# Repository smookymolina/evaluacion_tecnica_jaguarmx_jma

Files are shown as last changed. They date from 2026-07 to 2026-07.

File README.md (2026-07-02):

# Sistema de Extracción de Aire Caliente para Gabinete de Telecomunicaciones
## Jaguar de México — Evaluación Técnica
**Candidato:** Ing. Jair Molina Arce  
**Fecha:** 30 de junio de 2026

---

## Descripción del Proyecto
Este proyecto consiste en el diseño físico y lógico (hardware y firmware) de un sistema de control automático para la extracción de aire caliente en un gabinete de telecomunicaciones. El sistema compara la temperatura interna (`TEMP_INT`) con la temperatura externa (`TEMP_EXT`) y gestiona de forma dinámica:
1. **Compuertas mecánicas:** Operadas por un actuador lineal DFRobot FIT0803 a través de un puente H Toshiba TB6612FNG.
2. **Extractor/Ventilador:** Ventilador industrial Mechatronics MR1238E48B-FSR (48V DC) controlado por modulación low-side con un MOSFET de potencia IRL520N.

El núcleo de control está basado en el microcontrolador **Seeed Studio XIAO RP2350**, programado en MicroPython con una arquitectura de Máquina de Estados Finitos (FSM) y supervisado por un watchdog timer por hardware (WDT).

---

## Estructura del Repositorio

- `firmware/`: Código fuente de control en MicroPython.
  - `main.py`: Punto de entrada, inicialización y gestión de fallos.
  - `fsm.py`: Implementación de la FSM (INIT, READING, COOLING, IDLE, ERROR).
  - `adc_ntc.py`: Adquisición analógica con promedio móvil (trimmed mean, N=8) y conversión Beta.
  - `dip_switch.py`: Configuración de setpoint de histéresis mediante DIP switch.
  - `hbridge.py`: Control de dirección y habilitación del actuador con alimentación segura al WDT.
  - `fan.py`: Módulo de conmutación del MOSFET del ventilador.
- `kicad/`: Archivos del diseño de hardware en KiCad v8/v9.
  - `PCB/PCB.kicad_pro`: Archivo de proyecto de KiCad.
  - `PCB/PCB.kicad_sch`: Esquemático del circuito (Componentes colocados, especificaciones y BOM al 100%).
  - `PCB/PCB.kicad_pcb`: Diseño físico del PCB.
  - `PCB/sym-lib-table`: Tabla de mapeo de librerías de símbolos.
- `datasheets/`: Especificaciones técnicas en markdown y PDFs de los componentes clave.
- `FASE2.1_Netlist_Corregido_JaguarMX.md`: Netlist blindado de interconexiones (verdad de referencia).
- `FASE3_Guia_Esquematico_KiCad_JaguarMX.md`: Guía de diseño del esquemático.
- `FASE4_Layout_PCB_KiCad_JaguarMX.md`: Guía para el trazado de PCB y distribución de componentes.
- `ETISEJr_JairMolina.md`: Respuestas de evaluación y bitácora de uso de IA.
- `EvaluacionTecnica_SistemasEmbebidosJr_JaguarDeMexico.pdf`: Documento de requerimientos oficiales.
- `Cronograma_EvaluacionTecnica_JairMolina.docx`: Planificación de las fases del examen.
- `parse_sch.py`: Script para extraer la BOM directamente del esquemático KiCad.
- `test_firmware.py` / `micropython.py` / `mock_*.py`: Entorno local de pruebas unitarias y mocks de hardware.
- `package_project.ps1`: Script automatizado para el empaquetado del entregable final.

---

## Modificaciones de Hardware Incorporadas (Fase 2.1)
- **[MOD-1] Remapeo de SW2:** Movido de GP7 (back pad inaccesible) a GP8 (castellación lateral del Seeed XIAO RP2350).
- **[MOD-2] Clamping de ADC:** Reemplazo de diodos TVS SMBJ3.3A por diodos Schottky duales BAT54S en configuración de clamp activo post-filtro.
- **[MOD-3] Inmunidad EMI en DIP Switch:** Pull-ups externas de 10kΩ y condensadores de bypass de 100nF en cada canal.
- **[MOD-4] Selector J9:** Reemplazo del puente de soldadura por un header de 3 pines para seleccionar control del Gate directo o con driver TC4420.
- **[MOD-5] Star Ground:** Unión única AGND-PGND mediante Net-Tie de cobre directo (0Ω), eliminando la ferrita.
- **[Desacoplo de U4 (Nuevo)] Capacitor C15:** Adición del capacitor de desacoplo `C15` (100nF, DNP por defecto) para alimentar adecuadamente al driver TC4420 si se decide poblar en Configuración Activa-B.
- **[Conexión GND U4 (Nuevo)] Corrección de Plano:** Enrutamiento de la tierra de U4 (GND, pines 1, 2, 4) al plano de potencia `PGND` (en lugar del plano analógico `AGND`) para evitar la inyección de ruidos transitorios de 6A pico en el plano sensible de lectura.
- **[Consolidación (Nuevo)] Remoción de Excesos:** Eliminación de la resistencia fantasma redundante `R8` del diseño del circuito.

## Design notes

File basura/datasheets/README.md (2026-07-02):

# Datasheets — Sistema de Extracción de Aire Caliente
**Jaguar de México — Evaluación Técnica — Ing. Jair Molina Arce**

> Los archivos de esta carpeta son referencias técnicas para cada componente del sistema.
> Se incluyen dos fuentes por componente donde fue posible.
> **Los PDFs deben descargarse manualmente desde los links oficiales listados en cada archivo.**

---

## Índice de componentes

| Componente | Archivo | Función en el sistema |
|---|---|---|
| TB6612FNG | [TB6612FNG.md](TB6612FNG.md) | Puente H — control actuador FIT0803 |
| NTC TT05-10KC8-1S-T105-1500 | [NTC_TT05.md](NTC_TT05.md) | Sensor de temperatura ×2 |
| FIT0803 | [FIT0803.md](FIT0803.md) | Actuador lineal — compuertas |
| MR1238E48B-FSR | [MR1238E48B-FSR.md](MR1238E48B-FSR.md) | Ventilador 48V |
| IRL520N | [IRL520N.md](IRL520N.md) | MOSFET NMOS — etapa potencia ventilador |
| Seeed XIAO RP2350 | [XIAO_RP2350.md](XIAO_RP2350.md) | MCU (sesión en vivo) |
| RP2040 / Raspberry Pi Pico | [RP2040_Pico.md](RP2040_Pico.md) | MCU (simulación Wokwi) |
| AP2112K-3.3 | [AP2112K.md](AP2112K.md) | LDO 3.3V — regulador de tensión |
| 1N4007 | [1N4007.md](1N4007.md) | Diodo flyback — protección ventilador |
| SMBJ3.3A | [SMBJ3.3A.md](SMBJ3.3A.md) | TVS — protección entradas analógicas |

---

## Links de descarga directa (PDFs oficiales)

| Componente | Fuente 1 (oficial) | Fuente 2 (alternativa) |
|---|---|---|
| TB6612FNG | [Toshiba official](https://toshiba.semicon-storage.com/info/TB6612FNG_datasheet_en_20141001.pdf) | [SparkFun mirror](https://cdn.sparkfun.com/datasheets/Robotics/TB6612FNG.pdf) |
| NTC TT05 | [TME/TEWA official](https://www.tme.com/Document/878564d75c52f90722a06147eac94b00/TT05-10KC8-1S-T105-1500.pdf) | [DigiKey product page](https://www.digikey.com/en/products/detail/tewa-sensors-llc/TT05-10KC8-1S-T105-1500/10264792) |
| FIT0803 | [DFRobot (FIT080x series)](https://www.logosfoundation.org/instrum_gwr/sper/datasheets/DFRobot-FIT080x.pdf) | [DFRobot product page](https://www.dfrobot.com/product-2367.html) |
| MR1238E48B-FSR | [MinebeaMitsumi MR1238 series](https://www.mechatronics.com/pdf/MR1238.pdf) | [MinebeaMitsumi catalog](https://cdn.nmbtc.com/uploads/2025/04/202407-fan-motor-catalog-pdf.pdf) |
| IRL520N | [Infineon oficial](https://www.infineon.com/dgdl/Infineon-IRL520N-DataSheet-v01_01-EN.pdf?fileId=5546d462533600a40153565f9b62255b) | [Infineon assets](https://www.infineon.com/assets/row/public/documents/24/49/infineon-irl520n-datasheet-en.pdf) |
| XIAO RP2350 | [Seeed Studio Wiki](https://wiki.seeedstudio.com/getting-started-xiao-rp2350/) | [GitHub OSHW](https://github.com/Seeed-Studio/OSHW-XIAO-Series) |
| RP2040 | [RPi official](https://datasheets.raspberrypi.com/rp2040/rp2040-datasheet.pdf) | [Pico datasheet](https://datasheets.raspberrypi.com/pico/pico-datasheet.pdf) |
| AP2112K-3.3 | [Diodes Inc. official](https://www.diodes.com/assets/Datasheets/AP2112.pdf) | [Adafruit CDN](https://cdn-shop.adafruit.com/product-files/2471/AP2112.pdf) |
| 1N4007 | [Diodes Inc.](https://www.diodes.com/assets/Datasheets/ds28002.pdf) | [Mouser/Vishay](https://www.mouser.com/datasheet/2/149/1N4007-888322.pdf) |
| SMBJ3.3A | [Vishay SMBJ3V3](https://www.vishay.com/docs/88940/smbj3v3.pdf) | [Vishay SMBJ series](https://www.vishay.com/docs/88392/smbj.pdf) |

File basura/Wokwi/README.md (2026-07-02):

# Wokwi

Simulacion del sistema de ventilacion de aire caliente para Jaguar MX.

## Objetivo

La simulacion reproduce la logica del PDF de evaluacion:

- leer `TEMP_INT` y `TEMP_EXT`
- abrir compuertas y encender ventilador cuando `TEMP_INT > TEMP_EXT`
- apagar ventilador y cerrar compuertas cuando `TEMP_INT <= TEMP_EXT`
- entrar en estado seguro si alguna lectura NTC es invalida
- usar el DIP switch de 3 bits para seleccionar el setpoint de activación

## Archivos

- `diagram.json`: conexionado completo de la simulacion
- `sketch.ino`: firmware Arduino para Wokwi
- `tb6612fng-sim.chip.json`, `tb6612fng-sim.chip.c`: modelo del TB6612FNG
- `main.py`, `adc_ntc.py`, `dip_switch.py`, `fan.py`, `fsm.py`, `hbridge.py`: referencia MicroPython
- `MAPA_GPIO.md`: mapa rapido de pines

## Notas

- `GP26` y `GP27` simulan los NTC.
- `GP6`, `GP7` y `GP0` leen el DIP switch con `INPUT_PULLUP`.
- `GP2`, `GP1` y `GP3` controlan el TB6612FNG.
- `GP4` controla el ventilador simulado.
- `STBY` del TB6612FNG va fijo a `3V3`.
- Los LEDs de estado usan resistores en serie de `220 ohm`.

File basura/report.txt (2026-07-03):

Info: Procesando el símbolo 'C1:SparkFun-Capacitor:C_0805_2012Metric'.
Info: Procesando el símbolo 'C10:Capacitor_THT:CP_Radial_D6.3mm_P2.50mm'.
Info: Procesando el símbolo 'C6:SparkFun-Capacitor:C_0402_1005Metric'.
Info: Procesando el símbolo 'C12:SparkFun-Capacitor:C_0402_1005Metric'.
Info: Procesando el símbolo 'Q1:Package_TO_SOT_THT:TO-220-3_Vertical'.
Info: Procesando el símbolo 'R2:SparkFun-Resistor:R_0603_1608Metric'.
Info: Procesando el símbolo 'C4:SparkFun-Capacitor:C_0402_1005Metric'.
Info: Procesando el símbolo 'J1:Connector_JST:JST_PH_B2B-PH-K_1x02_P2.00mm_Vertical'.
Info: Procesando el símbolo 'J2:Connector_JST:JST_PH_B2B-PH-K_1x02_P2.00mm_Vertical'.
Info: Procesando el símbolo 'C14:SparkFun-Capacitor:C_0402_1005Metric'.
Info: Procesando el símbolo 'F1:Fuse:Fuse_1812_4532Metric'.
Info: Procesando el símbolo 'R1:SparkFun-Resistor:R_0603_1608Metric'.
Info: Procesando el símbolo 'C2:SparkFun-Capacitor:C_0805_2012Metric'.
Info: Procesando el símbolo 'D3:Diode_SMD:D_SMA'.
Info: Procesando el símbolo 'J3:SparkFun-Connector:ScrewTerminal_1x02_P3.5mm_Horizontal_Black'.
Info: Procesando el símbolo 'C9:SparkFun-Capacitor:C_0402_1005Metric'.
Info: Procesando el símbolo 'C7:SparkFun-Capacitor:C_0805_2012Metric'.
Info: Procesando el símbolo 'C11:Capacitor_SMD:C_0805_2012Metric'.
Info: Procesando el símbolo 'D2:Package_TO_SOT_SMD:SOT-23'.
Info: Procesando el símbolo 'C5:SparkFun-Capacitor:C_0402_1005Metric'.
Info: Procesando el símbolo 'J9:Connector_PinHeader_2.54mm:PinHeader_1x03_P2.54mm_Vertical'.
Info: Procesando el símbolo 'C13:SparkFun-Capacitor:C_0402_1005Metric'.
Info: Procesando el símbolo 'J7:SparkFun-Connector:ScrewTerminal_1x02_P3.5mm_Horizontal_Black'.
Info: Procesando el símbolo 'D1:Package_TO_SOT_SMD:SOT-23'.
Info: Procesando el símbolo 'C3:SparkFun-Capacitor:C_0402_1005Metric'.
Info: Procesando el símbolo 'J5:SparkFun-Connector:ScrewTerminal_1x02_P3.5mm_Horizontal_Black'.
Info: Procesando el símbolo 'NT1:NetTie:NetTie-2_SMD_Pad0.5mm'.
Info: Procesando el símbolo 'LED1:LED_SMD:LED_0805_2012Metric'.
Info: Procesando el símbolo 'C15:SparkFun-Capacitor:C_0402_1005Metric'.
Info: Procesando el símbolo 'J6:SparkFun-Connector:ScrewTerminal_1x02_P3.5mm_Horizontal_Black'.
Info: Procesando el símbolo 'C8:SparkFun-Capacitor:C_0402_1005Metric'.
Info: Procesando el símbolo 'R3:SparkFun-Resistor:R_0402_1005Metric'.
Info: Procesando el símbolo 'R4:SparkFun-Resistor:R_0402_1005Metric'.
Info: Procesando el símbolo 'R5:SparkFun-Resistor:R_0402_1005Metric'.
Info: Procesando el símbolo 'R6:SparkFun-Resistor:R_0402_1005Metric'.
Info: Procesando el símbolo 'R7:SparkFun-Resistor:R_0402_1005Metric'.
Info: Procesando el símbolo 'R9:SparkFun-Resistor:R_0402_1005Metric'.
Info: Procesando el símbolo 'R10:SparkFun-Resistor:R_0402_1005Metric'.
Info: Procesando el símbolo 'R11:SparkFun-Resistor:R_0402_1005Metric'.
Info: Procesando el símbolo 'R_LED1:SparkFun-Resistor:R_0402_1005Metric'.
Info: Procesando el símbolo 'SW1:Button_Switch_THT:SW_DIP_SPSTx03_Slide_9.78x9.8mm_W7.62mm_P2.54mm'.
Info: Procesando el símbolo 'TP1:SparkFun-Connector:TestPoint-1.25mm'.
Info: Procesando el símbolo 'TP2:SparkFun-Connector:TestPoint-1.25mm'.
Info: Procesando el símbolo 'TP3:SparkFun-Connector:TestPoint-1.25mm'.
Info: Procesando el símbolo 'TP4:SparkFun-Connector:TestPoint-1.25mm'.
Info: Procesando el símbolo 'TP5:SparkFun-Connector:TestPoint-1.25mm'.
Info: Procesando el símbolo 'TP6:SparkFun-Connector:TestPoint-1.25mm'.
Info: Procesando el símbolo 'TP7:SparkFun-Connector:TestPoint-1.25mm'.
Info: Procesando el símbolo 'TP8:SparkFun-Connector:TestPoint-1.25mm'.
Info: Procesando el símbolo 'U1:Jaguar_Custom:XIAO-RP2350-DIP'.
Info: Procesando el símbolo 'U2:SparkFun-Semiconductor-Standard:SOT23-5'.
Info: Procesando el símbolo 'U3:Package_SO:SSOP-24_5.3x8.2mm_P0.65mm'.
Info: Procesando el símbolo 'U4:Package_DIP:DIP-8_W7.62mm'.
Agregado C3 (huella 'SparkFun-Capacitor:C_0402_1005Metric').
Indicador de referencia cambiado de REF** a C3.
Valor C3 cambiado de C_0402_1005Metric a 0.1uF.
Asociación de símbolos C3 actualizada de  a /eef0f50d-1df9-4b00-8fcb-342aab38eab5.
Actualizar campos C3.
Se actualizó el nombre de la hoja C3 a '/'.
Se actualizó el archivo de hoja C3 a 'PCB.kicad_sch'.
Se actualizaron los filtros de huella de C3 a 'C_*'.
C3 pin 1 conectado a /AGND.
C3 pin 2 conectado a /+5V.
Se actualizaron los metadatos de unidad de C3.
Agregado C4 (huella 'SparkFun-Capacitor:C_0402_1005Metric').
Indicador de referencia cambiado de REF** a C4.
Valor C4 cambiado de C_0402_1005Metric a 0.1uF.
Asociación de símbolos C4 actualizada de  a /efd12b0c-3a97-4848-8e5b-246a40010ace.
Actualizar campos C4.
Se actualizó el nombre de la hoja C4 a '/'.
Se actualizó el archivo de hoja C4 a 'PCB.kicad_sch'.
Se actualizaron los filtros de huella de C4 a 'C_*'.
C4 pin 1 conectado a /NET_3V3_LDO.
C4 pin 2 conectado a /AGND.
Se actualizaron los metadatos de unidad de C4.
Agregado C5 (huella 'SparkFun-Capacitor:C_0402_1005Metric').
Indicador de referencia cambiado de REF** a C5.
Valor C5 cambiado de C_0402_1005Metric a 0.1uF.
Asociación de símbolos C5 actualizada de  a /d8a77b6c-06a9-469e-b575-1f42f5d62b60.
Actualizar campos C5.
Se actualizó el nombre de la hoja C5 a '/'.
Se actualizó el archivo de hoja C5 a 'PCB.kicad_sch'.
Se actualizaron los filtros de huella de C5 a 'C_*'.
C5 pin 1 conectado a /AGND.
C5 pin 2 conectado a /NET_TEMP_INT_FILT.
Se actualizaron los metadatos de unidad de C5.
Agregado C6 (huella 'SparkFun-Capacitor:C_0402_1005Metric').
Indicador de referencia cambiado de REF** a C6.
Valor C6 cambiado de C_0402_1005Metric a 0.1uF.
Asociación de símbolos C6 actualizada de  a /b0000001-0000-4000-8000-000000000005.
Actualizar campos C6.
Se actualizó el nombre de la hoja C6 a '/'.
Se actualizó el archivo de hoja C6 a 'PCB.kicad_sch'.
Se actualizaron los filtros de huella de C6 a 'C_*'.
C6 pin 1 conectado a /NET_TEMP_EXT_FILT.
C6 pin 2 conectado a /AGND.
Se actualizaron los metadatos de unidad de C6.
Agregado C7 (huella 'SparkFun-Capacitor:C_0805_2012Metric').
Indicador de referencia cambiado de REF** a C7.
Valor C7 cambiado de C_0805_2012Metric a 47uF.
Asociación de símbolos C7 actualizada de  a /b0000001-0000-4000-8000-000000000006.
Actualizar campos C7.
Se actualizó el nombre de la hoja C7 a '/'.
Se actualizó el archivo de hoja C7 a 'PCB.kicad_sch'.
Se actualizaron los filtros de huella de C7 a 'CP_*'.
C7 pin 2 conectado a /PGND.
C7 pin 1 conectado a /+5V.
Se actualizaron los metadatos de unidad de C7.
Agregado C8 (huella 'SparkFun-Capacitor:C_0402_1005Metric').
Indicador de referencia cambiado de REF** a C8.
Valor C8 cambiado de C_0402_1005Metric a 0.1uF.
Asociación de símbolos C8 actualizada de  a /b0000001-0000-4000-8000-000000000007.
Actualizar campos C8.
Se actualizó el nombre de la hoja C8 a '/'.
Se actualizó el archivo de hoja C8 a 'PCB.kicad_sch'.
Se actualizaron los filtros de huella de C8 a 'C_*'.
C8 pin 2 conectado a /PGND.
C8 pin 1 conectado a /+5V.
Se actualizaron los metadatos de unidad de C8.
Agregado C9 (huella 'SparkFun-Capacitor:C_0402_1005Metric').
Indicador de referencia cambiado de REF** a C9.
Valor C9 cambiado de C_0402_1005Metric a 0.1uF.
Asociación de símbolos C9 actualizada de  a /b0000001-0000-4000-8000-000000000008.
Actualizar campos C9.
Se actualizó el nombre de la hoja C9 a '/'.
Se actualizó el archivo de hoja C9 a 'PCB.kicad_sch'.
Se actualizaron los filtros de huella de C9 a 'C_*'.
C9 pin 1 conectado a /AGND.
C9 pin 2 conectado a /+3V3.
Se actualizaron los metadatos de unidad de C9.
Agregado C10 (huella 'Capacitor_THT:CP_Radial_D6.3mm_P2.50mm').
Indicador de referencia cambiado de REF** a C10.
Valor C10 cambiado de CP_Radial_D6.3mm_P2.50mm a 100uF/63V.
Asociación de símbolos C10 actualizada de  a /b0000001-0000-4000-8000-000000000009.
Actualizar campos C10.
Se actualizó el nombre de la hoja C10 a '/'.
Se actualizó el archivo de hoja C10 a 'PCB.kicad_sch'.
C10 pin 2 conectado a /PGND.
C10 pin 1 conectado a /+48V.
Se actualizaron los metadatos de unidad de C10.
Agregado C11 (huella 'Capacitor_SMD:C_0805_2012Metric').
Indicador de referencia cambiado de REF** a C11.
Valor C11 cambiado de C_0805_2012Metric a 100nF/63V.
Asociación de símbolos C11 actualizada de  a /b0000001-0000-4000-8000-00000000000a.
Actualizar campos C11.
Se actualizó el nombre de la hoja C11 a '/'.
Se actualizó el archivo de hoja C11 a 'PCB.kicad_sch'.
C11 pin 1 conectado a /+48V.
C11 pin 2 conectado a /PGND.
Se actualizaron los metadatos de unidad de C11.
Agregado C12 (huella 'SparkFun-Capacitor:C_0402_1005Metric').
Indicador de referencia cambiado de REF** a C12.
Valor C12 cambiado de C_0402_1005Metric a 0.1uF.
Asociación de símbolos C12 actualizada de  a /b0000001-0000-4000-8000-00000000000b.
Actualizar campos C12.
Se actualizó el nombre de la hoja C12 a '/'.
Se actualizó el archivo de hoja C12 a 'PCB.kicad_sch'.
Se actualizaron los filtros de huella de C12 a 'C_*'.
C12 pin 1 conectado a /NET_SW1.
C12 pin 2 conectado a /AGND.
Se actualizaron los metadatos de unidad de C12.
Agregado C13 (huella 'SparkFun-Capacitor:C_0402_1005Metric').
Indicador de referencia cambiado de REF** a C13.
Valor C13 cambiado de C_0402_1005Metric a 0.1uF.
Asociación de símbolos C13 actualizada de  a /b0000001-0000-4000-8000-00000000000c.
Actualizar campos C13.
Se actualizó el nombre de la hoja C13 a '/'.
Se actualizó el archivo de hoja C13 a 'PCB.kicad_sch'.
Se actualizaron los filtros de huella de C13 a 'C_*'.
C13 pin 2 conectado a /AGND.
C13 pin 1 conectado a /NET_SW2.
Se actualizaron los metadatos de unidad de C13.
Agregado C14 (huella 'SparkFun-Capacitor:C_0402_1005Metric').
Indicador de referencia cambiado de REF** a C14.
Valor C14 cambiado de C_0402_1005Metric a 0.1uF.
Asociación de símbolos C14 actualizada de  a /b0000001-0000-4000-8000-00000000000d.
Actualizar campos C14.
Se actualizó el nombre de la hoja C14 a '/'.
Se actualizó el archivo de hoja C14 a 'PCB.kicad_sch'.
Se actualizaron los filtros de huella de C14 a 'C_*'.
C14 pin 2 conectado a /AGND.
C14 pin 1 conectado a /NET_SW3.
Se actualizaron los metadatos de unidad de C14.
Agregado C15 (huella 'SparkFun-Capacitor:C_0402_1005Metric').
Indicador de referencia cambiado de REF** a C15.
Valor C15 cambiado de C_0402_1005Metric a 0.1uF.
Asociación de símbolos C15 actualizada de  a /b1b4b5f3-0996-47f9-902e-aba3ce2c80ba.
Actualizar campos C15.
Se actualizó el nombre de la hoja C15 a '/'.
Se actualizó el archivo de hoja C15 a 'PCB.kicad_sch'.
Se actualizaron los filtros de huella de C15 a 'C_*'.
Agregar el atributo de fabricación 'no colocar' C15.
C15 pin 1 conectado a /+5V.
C15 pin 2 conectado a /PGND.
Se actualizaron los metadatos de unidad de C15.
Agregado D1 (huella 'Package_TO_SOT_SMD:SOT-23').
Indicador de referencia cambiado de REF** a D1.
Valor D1 cambiado de SOT-23 a BAT54S.
Asociación de símbolos D1 actualizada de  a /aa939b38-faeb-4cf1-a10b-2f30e4802bd6.
Actualizar campos D1.
Se actualizó el nombre de la hoja D1 a '/'.
Se actualizó el archivo de hoja D1 a 'PCB.kicad_sch'.
Se actualizaron los filtros de huella de D1 a 'SOT?23*'.
D1 pin 1 conectado a /AGND.
D1 pin 2 conectado a /+3V3.
D1 pin 3 conectado a /NET_TEMP_INT_FILT.
Se actualizaron los metadatos de unidad de D1.
Agregado D2 (huella 'Package_TO_SOT_SMD:SOT-23').
Indicador de referencia cambiado de REF** a D2.
Valor D2 cambiado de SOT-23 a BAT54S.
Asociación de símbolos D2 actualizada de  a /e25ee7cd-9fc6-4a12-885c-602e5b6667bb.
Actualizar campos D2.
Se actualizó el nombre de la hoja D2 a '/'.
Se actualizó el archivo de hoja D2 a 'PCB.kicad_sch'.
Se actualizaron los filtros de huella de D2 a 'SOT?23*'.
D2 pin 3 conectado a /NET_TEMP_EXT_FILT.
D2 pin 2 conectado a /+3V3.
D2 pin 1 conectado a /AGND.
Se actualizaron los metadatos de unidad de D2.
Agregado D3 (huella 'Diode_SMD:D_SMA').
Indicador de referencia cambiado de REF** a D3.
Valor D3 cambiado de D_SMA a US1M.
Asociación de símbolos D3 actualizada de  a /60366eec-ba0f-4d0d-9a4b-f3821b28c411.
Actualizar campos D3.
Se actualizó el nombre de la hoja D3 a '/'.
Se actualizó el archivo de hoja D3 a 'PCB.kicad_sch'.
Se actualizaron los filtros de huella de D3 a 'D*SMA*'.
D3 pin 2 conectado a /NET_FAN_HS.
D3 pin 1 conectado a /+48V.
Se actualizaron los metadatos de unidad de D3.
Agregado F1 (huella 'Fuse:Fuse_1812_4532Metric').
Indicador de referencia cambiado de REF** a F1.
Valor F1 cambiado de Fuse_1812_4532Metric a 500mA.
Asociación de símbolos F1 actualizada de  a /b0000001-0000-4000-8000-000000000002.
Actualizar campos F1.
Se actualizó el nombre de la hoja F1 a '/'.
Se actualizó el archivo de hoja F1 a 'PCB.kicad_sch'.
F1 pin 1 conectado a /NET_3V3_LDO.
F1 pin 2 conectado a /+3V3.
Se actualizaron los metadatos de unidad de F1.
Agregado J1 (huella 'Connector_JST:JST_PH_B2B-PH-K_1x02_P2.00mm_Vertical').
Indicador de referencia cambiado de REF** a J1.
Valor J1 cambiado de JST_PH_B2B-PH-K_1x02_P2.00mm_Vertical a JST_2mm.
Asociación de símbolos J1 actualizada de  a /de3872d7-af1a-4fc6-b4de-6b86069a6122.
Actualizar campos J1.
Se actualizó el nombre de la hoja J1 a '/'.
Se actualizó el archivo de hoja J1 a 'PCB.kicad_sch'.
Se actualizaron los filtros de huella de J1 a 'Connector*:*_1x??_*'.
J1 pin 2 conectado a /AGND.
J1 pin 1 conectado a /NET_TEMP_INT_DIV.
Se actualizaron los metadatos de unidad de J1.
Agregado J2 (huella 'Connector_JST:JST_PH_B2B-PH-K_1x02_P2.00mm_Vertical').
Indicador de referencia cambiado de REF** a J2.
Valor J2 cambiado de JST_PH_B2B-PH-K_1x02_P2.00mm_Vertical a JST_2mm.
Asociación de símbolos J2 actualizada de  a /08fcfca9-1ee1-4c31-9444-628b76b9f055.
Actualizar campos J2.
Se actualizó el nombre de la hoja J2 a '/'.
Se actualizó el archivo de hoja J2 a 'PCB.kicad_sch'.
Se actualizaron los filtros de huella de J2 a 'Connector*:*_1x??_*'.
J2 pin 2 conectado a /NET_TEMP_EXT_DIV.
J2 pin 1 conectado a /AGND.
Se actualizaron los metadatos de unidad de J2.
Agregado J3 (huella 'SparkFun-Connector:ScrewTerminal_1x02_P3.5mm_Horizontal_Black').
Indicador de referencia cambiado de REF** a J3.
Valor J3 cambiado de Screw_Terminal_3.5mm-2 a 3.5mm.
Asociación de símbolos J3 actualizada de  a /34c2b381-5b12-41a2-906a-516ca9d94013.
Actualizar campos J3.
Se actualizó el nombre de la hoja J3 a '/'.
Se actualizó el archivo de hoja J3 a 'PCB.kicad_sch'.
Se actualizaron los filtros de huella de J3 a 'TerminalBlock*:*'.
J3 pin 1 conectado a /NET_AO1.
J3 pin 2 conectado a /NET_AO2.
Se actualizaron los metadatos de unidad de J3.
Agregado J5 (huella 'SparkFun-Connector:ScrewTerminal_1x02_P3.5mm_Horizontal_Black').
Indicador de referencia cambiado de REF** a J5.
Valor J5 cambiado de Screw_Terminal_3.5mm-2 a Ventilador.
Asociación de símbolos J5 actualizada de  a /b0000001-0000-4000-8000-00000000000e.
Se actualizó el nombre de la hoja J5 a '/'.
Se actualizó el archivo de hoja J5 a 'PCB.kicad_sch'.
Se actualizaron los filtros de huella de J5 a 'TerminalBlock*:*'.
J5 pin 1 conectado a /+48V.
J5 pin 2 conectado a /NET_FAN_HS.
Se actualizaron los metadatos de unidad de J5.
Agregado J6 (huella 'SparkFun-Connector:ScrewTerminal_1x02_P3.5mm_Horizontal_Black').
Indicador de referencia cambiado de REF** a J6.
Valor J6 cambiado de Screw_Terminal_3.5mm-2 a 48V IN.
Asociación de símbolos J6 actualizada de  a /4e73bc36-87a5-4770-ad93-4f481c7e6480.
Actualizar campos J6.
Se actualizó el nombre de la hoja J6 a '/'.
Se actualizó el archivo de hoja J6 a 'PCB.kicad_sch'.
Se actualizaron los filtros de huella de J6 a 'TerminalBlock*:*'.
J6 pin 1 conectado a /+48V.
J6 pin 2 conectado a /PGND.
Se actualizaron los metadatos de unidad de J6.
Agregado J7 (huella 'SparkFun-Connector:ScrewTerminal_1x02_P3.5mm_Horizontal_Black').
Indicador de referencia cambiado de REF** a J7.
Valor J7 cambiado de Screw_Terminal_3.5mm-2 a 3.5mm.
Asociación de símbolos J7 actualizada de  a /bcbd1006-a28c-43f5-9b52-2a5d790b5a48.
Actualizar campos J7.
Se actualizó el nombre de la hoja J7 a '/'.
Se actualizó el archivo de hoja J7 a 'PCB.kicad_sch'.
Se actualizaron los filtros de huella de J7 a 'TerminalBlock*:*'.
J7 pin 2 conectado a /PGND.
J7 pin 1 conectado a /+5V.
Se actualizaron los metadatos de unidad de J7.
Agregado J9 (huella 'Connector_PinHeader_2.54mm:PinHeader_1x03_P2.54mm_Vertical').
Indicador de referencia cambiado de REF** a J9.
Valor J9 cambiado de PinHeader_1x03_P2.54mm_Vertical a Selector_TC4420.
Asociación de símbolos J9 actualizada de  a /b0000001-0000-4000-8000-00000000000f.
Actualizar campos J9.
Se actualizó el nombre de la hoja J9 a '/'.
Se actualizó el archivo de hoja J9 a 'PCB.kicad_sch'.
J9 pin 1 conectado a /NET_VENT.
J9 pin 3 conectado a /NET_VENT_DRV.
J9 pin 2 conectado a /NET_VENT_GATE.
Se actualizaron los metadatos de unidad de J9.
Agregado LED1 (huella 'LED_SMD:LED_0805_2012Metric').
Indicador de referencia cambiado de REF** a LED1.
Valor LED1 cambiado de LED_0805_2012Metric a LED_Green.
Asociación de símbolos LED1 actualizada de  a /1394c127-4793-4a3e-8680-3f4560613927.
Actualizar campos LED1.
Se actualizó el nombre de la hoja LED1 a '/'.
Se actualizó el archivo de hoja LED1 a 'PCB.kicad_sch'.
Se actualizaron los filtros de huella de LED1 a 'LED* LED_SMD:* LED_THT:*'.
LED1 pin 2 conectado a /NET_LED_ANODE.
LED1 pin 1 conectado a /AGND.
Se actualizaron los metadatos de unidad de LED1.
Agregado NT1 (huella 'NetTie:NetTie-2_SMD_Pad0.5mm').
Indicador de referencia cambiado de REF** a NT1.
Valor NT1 cambiado de NetTie-2_SMD_Pad0.5mm a NetTie_2.
Asociación de símbolos NT1 actualizada de  a /a79ef54c-0734-4923-bbe9-873fdc25d9f5.
Actualizar campos NT1.
Se actualizó el nombre de la hoja NT1 a '/'.
Se actualizó el archivo de hoja NT1 a 'PCB.kicad_sch'.
Se actualizaron los filtros de huella de NT1 a 'Net*Tie*'.
Atributo de fabricación 'excluir de los archivos de posición' NT1 eliminado.
NT1 pin 2 conectado a /PGND.
NT1 pin 1 conectado a /AGND.
Se actualizaron los metadatos de unidad de NT1.
Agregado Q1 (huella 'Package_TO_SOT_THT:TO-220-3_Vertical').
Indicador de referencia cambiado de REF** a Q1.
Valor Q1 cambiado de TO-220-3_Vertical a IRL520N.
Asociación de símbolos Q1 actualizada de  a /b0000001-0000-4000-8000-000000000001.
Actualizar campos Q1.
Se actualizó el nombre de la hoja Q1 a '/'.
Se actualizó el archivo de hoja Q1 a 'PCB.kicad_sch'.
Q1 pin 3 conectado a /PGND.
Q1 pin 1 conectado a /NET_Q1_GATE.
Q1 pin 2 conectado a /NET_FAN_HS.
Se actualizaron los metadatos de unidad de Q1.
Agregado R1 (huella 'SparkFun-Resistor:R_0603_1608Metric').
Indicador de referencia cambiado de REF** a R1.
Valor R1 cambiado de R_0603_1608Metric a 10k 0.1%.
Asociación de símbolos R1 actualizada de  a /ef87274d-93e4-4979-a0d1-2723f46ad4b7.
Actualizar campos R1.
Se actualizó el nombre de la hoja R1 a '/'.
Se actualizó el archivo de hoja R1 a 'PCB.kicad_sch'.
Se actualizaron los filtros de huella de R1 a 'R_*'.
R1 pin 2 conectado a /NET_TEMP_INT_DIV.
R1 pin 1 conectado a /+3V3.
Se actualizaron los metadatos de unidad de R1.
Agregado R2 (huella 'SparkFun-Resistor:R_0603_1608Metric').
Indicador de referencia cambiado de REF** a R2.
Valor R2 cambiado de R_0603_1608Metric a 10k 0.1%.
Asociación de símbolos R2 actualizada de  a /7eda99b9-30ca-4297-9b73-5824523d8969.
Actualizar campos R2.
Se actualizó el nombre de la hoja R2 a '/'.
Se actualizó el archivo de hoja R2 a 'PCB.kicad_sch'.
Se actualizaron los filtros de huella de R2 a 'R_*'.
R2 pin 2 conectado a /+3V3.
R2 pin 1 conectado a /NET_TEMP_EXT_DIV.
Se actualizaron los metadatos de unidad de R2.
Agregado C1 (huella 'SparkFun-Capacitor:C_0805_2012Metric').
Agregado R3 (huella 'SparkFun-Resistor:R_0402_1005Metric').
Indicador de referencia cambiado de REF** a R3.
Valor R3 cambiado de R_0402_1005Metric a 1k.
Asociación de símbolos R3 actualizada de  a /58419cf8-0382-451e-87fa-9297cabe991c.
Actualizar campos R3.
Se actualizó el nombre de la hoja R3 a '/'.
Se actualizó el archivo de hoja R3 a 'PCB.kicad_sch'.
Se actualizaron los filtros de huella de R3 a 'R_*'.
R3 pin 2 conectado a /NET_TEMP_INT_FILT.
R3 pin 1 conectado a /NET_TEMP_INT_DIV.
Se actualizaron los metadatos de unidad de R3.
Indicador de referencia cambiado de REF** a C1.
Agregado R4 (huella 'SparkFun-Resistor:R_0402_1005Metric').
Indicador de referencia cambiado de REF** a R4.
Valor R4 cambiado de R_0402_1005Metric a 1k.
Asociación de símbolos R4 actualizada de  a /a7723a2b-352d-4367-997a-362528bd109f.
Actualizar campos R4.
Se actualizó el nombre de la hoja R4 a '/'.
Se actualizó el archivo de hoja R4 a 'PCB.kicad_sch'.
Se actualizaron los filtros de huella de R4 a 'R_*'.
R4 pin 1 conectado a /NET_TEMP_EXT_DIV.
R4 pin 2 conectado a /NET_TEMP_EXT_FILT.
Se actualizaron los metadatos de unidad de R4.
Valor C1 cambiado de C_0805_2012Metric a 10uF.
Agregado R5 (huella 'SparkFun-Resistor:R_0402_1005Metric').
Indicador de referencia cambiado de REF** a R5.
Valor R5 cambiado de R_0402_1005Metric a 10k.
Asociación de símbolos R5 actualizada de  a /3319c6a0-3e7c-4e65-b16b-eed124d72bba.
Actualizar campos R5.
Se actualizó el nombre de la hoja R5 a '/'.
Se actualizó el archivo de hoja R5 a 'PCB.kicad_sch'.
Se actualizaron los filtros de huella de R5 a 'R_*'.
R5 pin 1 conectado a /+3V3.
R5 pin 2 conectado a /NET_STBY.
Se actualizaron los metadatos de unidad de R5.
Asociación de símbolos C1 actualizada de  a /d28bdcc9-22f2-40d2-8dcd-1e616402d41b.
Agregado R6 (huella 'SparkFun-Resistor:R_0402_1005Metric').
Indicador de referencia cambiado de REF** a R6.
Valor R6 cambiado de R_0402_1005Metric a 330R.
Asociación de símbolos R6 actualizada de  a /59017754-93ac-4200-9adb-343a8118174d.
Actualizar campos R6.
Se actualizó el nombre de la hoja R6 a '/'.
Se actualizó el archivo de hoja R6 a 'PCB.kicad_sch'.
Se actualizaron los filtros de huella de R6 a 'R_*'.
R6 pin 2 conectado a /NET_Q1_GATE.
R6 pin 1 conectado a /NET_VENT_GATE.
Se actualizaron los metadatos de unidad de R6.
Actualizar campos C1.
Agregado R7 (huella 'SparkFun-Resistor:R_0402_1005Metric').
Indicador de referencia cambiado de REF** a R7.
Valor R7 cambiado de R_0402_1005Metric a 10k.
Asociación de símbolos R7 actualizada de  a /c39d2313-1c66-40c5-b410-6103c4dd1fb4.
Actualizar campos R7.
Se actualizó el nombre de la hoja R7 a '/'.
Se actualizó el archivo de hoja R7 a 'PCB.kicad_sch'.
Se actualizaron los filtros de huella de R7 a 'R_*'.
R7 pin 1 conectado a /PGND.
R7 pin 2 conectado a /NET_Q1_GATE.
Se actualizaron los metadatos de unidad de R7.
Se actualizó el nombre de la hoja C1 a '/'.
Agregado R9 (huella 'SparkFun-Resistor:R_0402_1005Metric').
Indicador de referencia cambiado de REF** a R9.
Valor R9 cambiado de R_0402_1005Metric a 10k.
Asociación de símbolos R9 actualizada de  a /654b1512-eaa8-4f8a-a28d-79fe5cb3574d.
Actualizar campos R9.
Se actualizó el nombre de la hoja R9 a '/'.
Se actualizó el archivo de hoja R9 a 'PCB.kicad_sch'.
Se actualizaron los filtros de huella de R9 a 'R_*'.
R9 pin 2 conectado a /+3V3.
R9 pin 1 conectado a /NET_SW1.
Se actualizaron los metadatos de unidad de R9.
Se actualizó el archivo de hoja C1 a 'PCB.kicad_sch'.
Agregado R10 (huella 'SparkFun-Resistor:R_0402_1005Metric').
Indicador de referencia cambiado de REF** a R10.
Valor R10 cambiado de R_0402_1005Metric a 10k.
Asociación de símbolos R10 actualizada de  a /4734aacd-62b6-49d7-96fe-85ce4e4883e7.
Actualizar campos R10.
Se actualizó el nombre de la hoja R10 a '/'.
Se actualizó el archivo de hoja R10 a 'PCB.kicad_sch'.
Se actualizaron los filtros de huella de R10 a 'R_*'.
R10 pin 1 conectado a /NET_SW2.
R10 pin 2 conectado a /+3V3.
Se actualizaron los metadatos de unidad de R10.
Se actualizaron los filtros de huella de C1 a 'C_*'.
Agregado R11 (huella 'SparkFun-Resistor:R_0402_1005Metric').
Indicador de referencia cambiado de REF** a R11.
Valor R11 cambiado de R_0402_1005Metric a 10k.
Asociación de símbolos R11 actualizada de  a /433c2061-3094-4b3f-9d81-20513f9d12fd.
Actualizar campos R11.
Se actualizó el nombre de la hoja R11 a '/'.
Se actualizó el archivo de hoja R11 a 'PCB.kicad_sch'.
Se actualizaron los filtros de huella de R11 a 'R_*'.
R11 pin 1 conectado a /NET_SW3.
R11 pin 2 conectado a /+3V3.
Se actualizaron los metadatos de unidad de R11.
C1 pin 1 conectado a /+5V.
Agregado R_LED1 (huella 'SparkFun-Resistor:R_0402_1005Metric').
Indicador de referencia cambiado de REF** a R_LED1.
Valor R_LED1 cambiado de R_0402_1005Metric a 1k.
Asociación de símbolos R_LED1 actualizada de  a /b0000001-0000-4000-8000-000000000003.
Actualizar campos R_LED1.
Se actualizó el nombre de la hoja R_LED1 a '/'.
Se actualizó el archivo de hoja R_LED1 a 'PCB.kicad_sch'.
Se actualizaron los filtros de huella de R_LED1 a 'R_*'.
R_LED1 pin 1 conectado a /+3V3.
R_LED1 pin 2 conectado a /NET_LED_ANODE.
Se actualizaron los metadatos de unidad de R_LED1.
C1 pin 2 conectado a /AGND.
Agregado SW1 (huella 'Button_Switch_THT:SW_DIP_SPSTx03_Slide_9.78x9.8mm_W7.62mm_P2.54mm').
Indicador de referencia cambiado de REF** a SW1.
Valor SW1 cambiado de SW_DIP_SPSTx03_Slide_9.78x9.8mm_W7.62mm_P2.54mm a SW_DIP_x03.
Asociación de símbolos SW1 actualizada de  a /3c760929-8919-4f13-92a9-751186a496a8.
Actualizar campos SW1.
Se actualizó el nombre de la hoja SW1 a '/'.
Se actualizó el archivo de hoja SW1 a 'PCB.kicad_sch'.
Se actualizaron los filtros de huella de SW1 a 'SW?DIP?x3*'.
SW1 pin 3 conectado a /NET_SW3.
SW1 pin 2 conectado a /AGND.
SW1 pin 6 conectado a /AGND.
SW1 pin 1 conectado a /NET_SW1.
SW1 pin 5 conectado a /NET_SW2.
SW1 pin 4 conectado a /AGND.
Se actualizaron los metadatos de unidad de SW1.
Se actualizaron los metadatos de unidad de C1.
Agregado TP1 (huella 'SparkFun-Connector:TestPoint-1.25mm').
Indicador de referencia cambiado de Ref** a TP1.
Valor TP1 cambiado de Val** a 1.25mm.
Asociación de símbolos TP1 actualizada de  a /6e7a7608-9350-4a5a-9c0e-5b28a390c1f7.
Actualizar campos TP1.
Se actualizó el nombre de la hoja TP1 a '/'.
Se actualizó el archivo de hoja TP1 a 'PCB.kicad_sch'.
Se actualizaron los filtros de huella de TP1 a 'Pin* Test*'.
Atributo de fabricación 'excluir de la lista de materiales' TP1 eliminado.
Atributo de fabricación 'No colocar' TP1 eliminado.
Atributo de fabricación 'excluir de los archivos de posición' TP1 eliminado.
TP1 pin 1 conectado a /+3V3.
Se actualizaron los metadatos de unidad de TP1.
Agregado C2 (huella 'SparkFun-Capacitor:C_0805_2012Metric').
Agregado TP2 (huella 'SparkFun-Connector:TestPoint-1.25mm').
Indicador de referencia cambiado de Ref** a TP2.
Valor TP2 cambiado de Val** a 1.25mm.
Asociación de símbolos TP2 actualizada de  a /7cf0cb75-eb4c-40e1-9c13-e8be7d13fb0a.
Actualizar campos TP2.
Se actualizó el nombre de la hoja TP2 a '/'.
Se actualizó el archivo de hoja TP2 a 'PCB.kicad_sch'.
Se actualizaron los filtros de huella de TP2 a 'Pin* Test*'.
Atributo de fabricación 'excluir de la lista de materiales' TP2 eliminado.
Atributo de fabricación 'No colocar' TP2 eliminado.
Atributo de fabricación 'excluir de los archivos de posición' TP2 eliminado.
TP2 pin 1 conectado a /+5V.
Se actualizaron los metadatos de unidad de TP2.
Indicador de referencia cambiado de REF** a C2.
Agregado TP3 (huella 'SparkFun-Connector:TestPoint-1.25mm').
Indicador de referencia cambiado de Ref** a TP3.
Valor TP3 cambiado de Val** a 1.25mm.
Asociación de símbolos TP3 actualizada de  a /52612a82-b7ed-4682-a3ee-012e9091b870.
Actualizar campos TP3.
Se actualizó el nombre de la hoja TP3 a '/'.
Se actualizó el archivo de hoja TP3 a 'PCB.kicad_sch'.
Se actualizaron los filtros de huella de TP3 a 'Pin* Test*'.
Atributo de fabricación 'excluir de la lista de materiales' TP3 eliminado.
Atributo de fabricación 'No colocar' TP3 eliminado.
Atributo de fabricación 'excluir de los archivos de posición' TP3 eliminado.
TP3 pin 1 conectado a /+48V.
Se actualizaron los metadatos de unidad de TP3.
Valor C2 cambiado de C_0805_2012Metric a 10uF.
Agregado TP4 (huella 'SparkFun-Connector:TestPoint-1.25mm').
Indicador de referencia cambiado de Ref** a TP4.
Valor TP4 cambiado de Val** a 1.25mm.
Asociación de símbolos TP4 actualizada de  a /b828ddd2-cd7a-492e-87c3-f6cbdfa215c0.
Actualizar campos TP4.
Se actualizó el nombre de la hoja TP4 a '/'.
Se actualizó el archivo de hoja TP4 a 'PCB.kicad_sch'.
Se actualizaron los filtros de huella de TP4 a 'Pin* Test*'.
Atributo de fabricación 'excluir de la lista de materiales' TP4 eliminado.
Atributo de fabricación 'No colocar' TP4 eliminado.
Atributo de fabricación 'excluir de los archivos de posición' TP4 eliminado.
TP4 pin 1 conectado a /PGND.
Se actualizaron los metadatos de unidad de TP4.
Asociación de símbolos C2 actualizada de  a /933d6fc0-9052-48ae-83b3-e0a71c5a6fa6.
Agregado TP5 (huella 'SparkFun-Connector:TestPoint-1.25mm').
Indicador de referencia cambiado de Ref** a TP5.
Valor TP5 cambiado de Val** a 1.25mm.
Asociación de símbolos TP5 actualizada de  a /c405b527-ecb0-4578-9dbd-050128ab244f.
Actualizar campos TP5.
Se actualizó el nombre de la hoja TP5 a '/'.
Se actualizó el archivo de hoja TP5 a 'PCB.kicad_sch'.
Se actualizaron los filtros de huella de TP5 a 'Pin* Test*'.
Atributo de fabricación 'excluir de la lista de materiales' TP5 eliminado.
Atributo de fabricación 'No colocar' TP5 eliminado.
Atributo de fabricación 'excluir de los archivos de posición' TP5 eliminado.
TP5 pin 1 conectado a /AGND.
Se actualizaron los metadatos de unidad de TP5.
Actualizar campos C2.
Agregado TP6 (huella 'SparkFun-Connector:TestPoint-1.25mm').
Indicador de referencia cambiado de Ref** a TP6.
Valor TP6 cambiado de Val** a 1.25mm.
Asociación de símbolos TP6 actualizada de  a /166bb7a8-beb5-4abd-bdab-30b7fc2c1258.
Actualizar campos TP6.
Se actualizó el nombre de la hoja TP6 a '/'.
Se actualizó el archivo de hoja TP6 a 'PCB.kicad_sch'.
Se actualizaron los filtros de huella de TP6 a 'Pin* Test*'.
Atributo de fabricación 'excluir de la lista de materiales' TP6 eliminado.
Atributo de fabricación 'No colocar' TP6 eliminado.
Atributo de fabricación 'excluir de los archivos de posición' TP6 eliminado.
TP6 pin 1 conectado a /NET_TEMP_INT_FILT.
Se actualizaron los metadatos de unidad de TP6.
Se actualizó el nombre de la hoja C2 a '/'.
Agregado TP7 (huella 'SparkFun-Connector:TestPoint-1.25mm').
Indicador de referencia cambiado de Ref** a TP7.
Valor TP7 cambiado de Val** a 1.25mm.
Asociación de símbolos TP7 actualizada de  a /d493d83d-dc0c-4707-ae44-15421bc37380.
Actualizar campos TP7.
Se actualizó el nombre de la hoja TP7 a '/'.
Se actualizó el archivo de hoja TP7 a 'PCB.kicad_sch'.
Se actualizaron los filtros de huella de TP7 a 'Pin* Test*'.
Atributo de fabricación 'excluir de la lista de materiales' TP7 eliminado.
Atributo de fabricación 'No colocar' TP7 eliminado.
Atributo de fabricación 'excluir de los archivos de posición' TP7 eliminado.
TP7 pin 1 conectado a /NET_TEMP_EXT_FILT.
Se actualizaron los metadatos de unidad de TP7.
Se actualizó el archivo de hoja C2 a 'PCB.kicad_sch'.
Agregado TP8 (huella 'SparkFun-Connector:TestPoint-1.25mm').
Indicador de referencia cambiado de Ref** a TP8.
Valor TP8 cambiado de Val** a 1.25mm.
Asociación de símbolos TP8 actualizada de  a /fb19d9b8-8fd5-4841-a6f8-3b13481250b1.
Actualizar campos TP8.
Se actualizó el nombre de la hoja TP8 a '/'.
Se actualizó el archivo de hoja TP8 a 'PCB.kicad_sch'.
Se actualizaron los filtros de huella de TP8 a 'Pin* Test*'.
Atributo de fabricación 'excluir de la lista de materiales' TP8 eliminado.
Atributo de fabricación 'No colocar' TP8 eliminado.
Atributo de fabricación 'excluir de los archivos de posición' TP8 eliminado.
TP8 pin 1 conectado a /NET_Q1_GATE.
Se actualizaron los metadatos de unidad de TP8.
Se actualizaron los filtros de huella de C2 a 'C_*'.
Agregado U1 (huella 'Jaguar_Custom:XIAO-RP2350-DIP').
Asociación de símbolos U1 actualizada de  a /4cb626c4-8f9d-4d92-a70e-9198fd5f8646.
Se actualizó el nombre de la hoja U1 a '/'.
Se actualizó el archivo de hoja U1 a 'PCB.kicad_sch'.
U1 pin 1 conectado a /NET_TEMP_INT_FILT.
U1 pin 7 conectado a /NET_SW3.
Agregar red unconnected-(U1-D12-Pad16).
U1 pin 16 conectado a unconnected-(U1-D12-Pad16).
U1 pin 10 conectado a /NET_VENT.
Agregar red unconnected-(U1-VBAT-Pad23).
U1 pin 23 conectado a unconnected-(U1-VBAT-Pad23).
U1 pin 9 conectado a /NET_AIN1.
U1 pin 5 conectado a /NET_SW1.
Agregar red unconnected-(U1-D3-Pad4).
U1 pin 4 conectado a unconnected-(U1-D3-Pad4).
U1 pin 12 conectado a /+3V3.
Agregar red unconnected-(U1-D11-Pad15).
U1 pin 15 conectado a unconnected-(U1-D11-Pad15).
U1 pin 11 conectado a /NET_MOTOR_EN.
Agregar red unconnected-(U1-D16-Pad20).
U1 pin 20 conectado a unconnected-(U1-D16-Pad20).
U1 pin 6 conectado a /NET_SW2.
Agregar red unconnected-(U1-D14-Pad18).
U1 pin 18 conectado a unconnected-(U1-D14-Pad18).
U1 pin 8 conectado a /NET_AIN2.
U1 pin 24 conectado a /AGND.
Agregar red unconnected-(U1-D17-Pad21).
U1 pin 21 conectado a unconnected-(U1-D17-Pad21).
Agregar red unconnected-(U1-D2-Pad3).
U1 pin 3 conectado a unconnected-(U1-D2-Pad3).
Agregar red unconnected-(U1-D18-Pad22).
U1 pin 22 conectado a unconnected-(U1-D18-Pad22).
Agregar red unconnected-(U1-D15-Pad19).
U1 pin 19 conectado a unconnected-(U1-D15-Pad19).
Agregar red unconnected-(U1-D13-Pad17).
U1 pin 17 conectado a unconnected-(U1-D13-Pad17).
U1 pin 13 conectado a /AGND.
Agregar red unconnected-(U1-VBUS-Pad14).
U1 pin 14 conectado a unconnected-(U1-VBUS-Pad14).
U1 pin 2 conectado a /NET_TEMP_EXT_FILT.
Se actualizaron los metadatos de unidad de U1.
C2 pin 2 conectado a /AGND.
Agregado U2 (huella 'SparkFun-Semiconductor-Standard:SOT23-5').
Indicador de referencia cambiado de REF** a U2.
Valor U2 cambiado de SOT23-5 a AP2112K-3.3.
Asociación de símbolos U2 actualizada de  a /00dd7062-188b-4688-b8de-310698704570.
Actualizar campos U2.
Se actualizó el nombre de la hoja U2 a '/'.
Se actualizó el archivo de hoja U2 a 'PCB.kicad_sch'.
Se actualizaron los filtros de huella de U2 a 'SOT?23?5*'.
Agregar red unconnected-(U2-NC-Pad4).
U2 pin 4 conectado a unconnected-(U2-NC-Pad4).
U2 pin 1 conectado a /+5V.
U2 pin 2 conectado a /AGND.
U2 pin 5 conectado a /NET_3V3_LDO.
U2 pin 3 conectado a /+5V.
Se actualizaron los metadatos de unidad de U2.
C2 pin 1 conectado a /NET_3V3_LDO.
Agregado U3 (huella 'Package_SO:SSOP-24_5.3x8.2mm_P0.65mm').
Indicador de referencia cambiado de REF** a U3.
Valor U3 cambiado de SSOP-24_5.3x8.2mm_P0.65mm a TB6612FNG.
Asociación de símbolos U3 actualizada de  a /ab6aa0ed-42de-438a-b33a-988e8d7b6e38.
Actualizar campos U3.
Se actualizó el nombre de la hoja U3 a '/'.
Se actualizó el archivo de hoja U3 a 'PCB.kicad_sch'.
Se actualizaron los filtros de huella de U3 a 'SSOP*5.3x8.2mm*P0.65mm*'.
Agregar red unconnected-(U3-BO2-Pad7).
U3 pin 8 conectado a unconnected-(U3-BO2-Pad7).
U3 pin 2 conectado a /NET_AO1.
U3 pin 18 conectado a /AGND.
U3 pin 21 conectado a /NET_AIN1.
Agregar red unconnected-(U3-BO1-Pad11).
U3 pin 11 conectado a unconnected-(U3-BO1-Pad11).
U3 pin 5 conectado a /NET_AO2.
U3 pin 19 conectado a /NET_STBY.
U3 pin 16 conectado a /AGND.
U3 pin 17 conectado a /AGND.
Agregar red unconnected-(U3-BO2-Pad7)_1.
U3 pin 7 conectado a unconnected-(U3-BO2-Pad7)_1.
U3 pin 3 conectado a /PGND.
U3 pin 20 conectado a /+3V3.
U3 pin 15 conectado a /AGND.
U3 pin 24 conectado a /+5V.
Agregar red unconnected-(U3-BO1-Pad11)_1.
U3 pin 12 conectado a unconnected-(U3-BO1-Pad11)_1.
U3 pin 4 conectado a /PGND.
U3 pin 6 conectado a /NET_AO2.
U3 pin 22 conectado a /NET_AIN2.
U3 pin 23 conectado a /NET_MOTOR_EN.
U3 pin 14 conectado a /+5V.
U3 pin 9 conectado a /PGND.
U3 pin 10 conectado a /PGND.
U3 pin 13 conectado a /+5V.
U3 pin 1 conectado a /NET_AO1.
Se actualizaron los metadatos de unidad de U3.
Se actualizaron los metadatos de unidad de C2.
Agregado U4 (huella 'Package_DIP:DIP-8_W7.62mm').
Indicador de referencia cambiado de REF** a U4.
Valor U4 cambiado de DIP-8_W7.62mm a TC4420.
Asociación de símbolos U4 actualizada de  a /b0000001-0000-4000-8000-000000000004.
Actualizar campos U4.
Se actualizó el nombre de la hoja U4 a '/'.
Se actualizó el archivo de hoja U4 a 'PCB.kicad_sch'.
Agregar el atributo de fabricación 'no colocar' U4.
U4 pin 4 conectado a /PGND.
U4 pin 6 conectado a /NET_VENT_DRV.
U4 pin 3 conectado a /NET_VENT.
U4 pin 2 conectado a /PGND.
U4 pin 8 conectado a /+5V.
U4 pin 5 conectado a /+5V.
U4 pin 7 conectado a /+5V.
U4 pin 1 conectado a /PGND.
Se actualizaron los metadatos de unidad de U4.

Info: Número de avisos: 0, errores: 0.

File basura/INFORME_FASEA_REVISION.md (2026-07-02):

# INFORME FASE A — Revisión de Esquemático + Referencias de Layout
**Proyecto:** Jaguar MX — Extractor de aire caliente | **Fecha:** 2026-07-02
**Archivo revisado:** `kicad/PCB/PCB.kicad_sch` (netlist generada con kicad-cli 10.0; ERC = 0 errores)

> ⚠️ **VEREDICTO: PAUSAR ANTES DE FASE B.** Se encontraron **2 errores críticos** (E1, E2) que deben corregirse en el esquemático antes de iniciar el layout.

---

## Sección 1: Verificación de Esquemático

### Bloque 1 — Sensores NTC y DIP switch

| Ítem | Estado | Evidencia |
|---|---|---|
| Divisor 10kΩ+10kΩ ambos canales | ✅ CUMPLE | R1/R2 (10k 0.1%) a +3V3; NTC externa a AGND vía J1/J2 |
| Pull-ups DIP en GP6/GP7/GP0 | ✅ CUMPLE | R9/R10/R11 10k a +3V3 + C12–C14 100nF (debounce). SW1→D4(GP6), SW2→D5(GP7), SW3→D6(GP0) ✓ |
| Filtro RC 1kΩ + capacitor | ✅ CUMPLE | R3/R4 1k + C5/C6 100nF a AGND (fc ≈ 1.6 kHz) |
| Diodos BAT54S | ✅ CUMPLE | D1/D2 en clamp correcto: pin1→AGND, pin2→+3V3, pin3→señal filtrada |

### Bloque 2 — TB6612FNG

| Ítem | Estado | Evidencia |
|---|---|---|
| AIN1→GP2, AIN2→GP1 | ✅ CUMPLE | NET_AIN1→U1.9(D8=GP2)→U3.21; NET_AIN2→U1.8(D7=GP1)→U3.22 |
| MOTOR_EN→GP3 | ❌ **NO CUMPLE — CRÍTICO E1** | NET_MOTOR_EN conectado a U1.10 = **D9 = GP4** (debe ser D10=GP3). Está **intercambiado con VENT** |
| STBY en HIGH | ✅ CUMPLE | R5 10k a +3V3 (pull-up, mejor que tie directo) |
| Desacoplo VM y VCC | ✅ CUMPLE | VM: C7 47µF + C8 100nF; VCC: C9 100nF |
| TVS en entradas | ❌ NO CUMPLE | No existe ningún SMBJ3.3A en el esquemático (CLAUDE.md lo exige en GP26/GP27). Mitigación parcial: BAT54S |

**Bonus verificado correcto:** canal B deshabilitado (PWMB/BIN1/BIN2 a GND), salidas A en paralelo (pines 1-2 y 5-6), PGND1/2 (pines 3,4,9,10) a PGND y GND lógico (pin 18) a AGND — separación de retornos bien pensada.

### Bloque 3 — Etapa ventilador (MOSFET)

| Ítem | Estado | Evidencia |
|---|---|---|
| NMOS accionable a 3.3V | ✅ CUMPLE | Q1 IRL520N (TO-220) |
| Pull-down 10k en gate | ✅ CUMPLE | R7 a PGND |
| R serie en gate | ⚠️ CUMPLE c/desviación | R6 = **330Ω** (checklist pedía 100Ω). Aceptable; documentar. Footprint del símbolo se llama "10k_0402" para un valor 330R → confuso para BOM |
| Diodo flyback | ✅ CUMPLE (mejorado) | D3 = **US1M** (ultrafast, SMA) en vez de 1N4007; orientación correcta (K→+48V, A→drain) |
| 100µF + 100nF en +48V | ✅ CUMPLE | C10 100µF/63V + C11 100nF/63V |
| VENT→GP4 | ❌ **NO CUMPLE — CRÍTICO E1** | NET_VENT conectado a U1.11 = **D10 = GP3**. Intercambiado con MOTOR_EN |
| Driver de gate U4 | ❌ **CRÍTICO E2** | Pinout del símbolo custom TC4420 **no corresponde al DIP-8 real** |

**E2 detallado — TC4420 (Microchip DS21419, DIP-8 real):** 1,8=VDD · 2=IN · 3=NC · 4,5=VSS · 6,7=OUT.
El símbolo custom tiene: 1,2,4=GND · 3=IN · 5,7,8=VDD · 6=OUT. Con el footprint `DIP-8_W7.62mm` asignado esto produce: **+5V al pin 5 (VSS real) = cortocircuito +5V–GND**, señal IN al pin 3 (NC real) = entrada al aire, y pin 2 (IN real) clavado a GND. **Corregir el símbolo antes de FASE B.**

### Bloque 4 — Fuente de alimentación

| Ítem | Estado | Evidencia |
|---|---|---|
| LDO AP2112K-3.3 | ✅ CUMPLE | U2, EN atado a +5V (entrada por J7) |
| PPTC en salida del LDO | ✅ CUMPLE | F1 500mA (1812): LDO out → F1 → +3V3 |
| Desacoplo in/out | ✅ CUMPLE (eléctrico) | C1/C3 entrada, C2/C4 salida. Proximidad ≤3mm se verifica en FASE B |
| Alimentación del XIAO | ⚠️ OBSERVACIÓN | +3V3 se **retroalimenta al pin 3V3 del XIAO** (U1.12, salida del LDO interno); VBUS (pin 14) sin conectar. Si se conecta USB con alimentación externa, dos LDOs quedan en paralelo. Recomendación: alimentar VBUS desde +5V (idealmente con Schottky de ORing) o documentar la restricción "no conectar USB con fuente externa" |

### Bloque 5 — Tierras

| Ítem | Estado | Evidencia |
|---|---|---|
| Net-Tie AGND↔PGND | ✅ CUMPLE | NT1 (NetTie-2_SMD_Pad0.5mm), único punto de unión |
| Separación por zonas | ✅ CUMPLE (esquema) | AGND: XIAO, LDO, sensores, DIP, GND lógico TB6612. PGND: TB6612 potencia, Q1, U4, rail 48V. Partición física → FASE B |

**ERC (kicad-cli, severidad error): 0 violaciones.** Nota menor: kicad-cli advierte errores de anotación (numeración de referencias salta J4 y J8) — re-anotar en el editor, cosmético.

### Acciones recomendadas (orden)
1. **E1:** Intercambiar las nets de U1.10 y U1.11 → MOTOR_EN a D10 (GP3), VENT a D9 (GP4). Referencia: `datasheets/XIAO_RP2350.md` (D9=GPIO4, D10=GPIO3). El firmware ya está correcto; el error es del esquemático.
2. **E2:** Rehacer el símbolo `jaguar_power:TC4420` con el pinout real del DIP-8.
3. Agregar TVS SMBJ3.3A en GP26/GP27 (spec del proyecto) o documentar formalmente la desviación con BAT54S como protección alternativa.
4. Decidir estrategia de alimentación del XIAO (VBUS vs backfeed 3V3) y documentarla.
5. Corregir nombre de footprint de R6 y re-anotar referencias.

---

## Sección 2: Referencias de Layout (mixed-signal, 2 capas)

> Corrección de fuente: el "AN-95 de Analog Devices" citado en el prompt no existe con ese nombre. Las referencias reales de ADI son **MT-031**, **MT-101** y el artículo de Analog Dialogue sobre layout mixed-signal (abajo).

| # | Referencia | Tipo | Aporte clave para Jaguar |
|---|---|---|---|
| 1 | [SparkFun Dual TB6612FNG](https://github.com/sparkfun/Motor_Driver-Dual_TB6612FNG) (OSHW, Eagle, 2 capas) | Breakout mismo IC | Colocación de desacoplo VM pegado a pines 13/14/24, salidas de motor con pistas anchas y cortas, plano GND trasero continuo |
| 2 | [FanPico — tjko/fanpico](https://github.com/tjko/fanpico) (OSHW, KiCad, RP2040) | Controlador de ventiladores RP2040 | Partición conector-de-potencia-en-borde / MCU-al-centro; archivos KiCad completos para estudiar netclasses y zonas en FASE B |
| 3 | [Starfish — blog.thea.codes](https://blog.thea.codes/starfish-a-control-board-with-the-rp2040/) (RP2040 + drivers de motor) | Placa de control con motores | Flyback Schottky junto al conector del motor (lazo mínimo), separación señal/potencia documentada paso a paso |
| 4 | [MITAYI Pico RP2040 — CIRCUITSTATE](https://www.circuitstate.com/projects/mitayi-pico-rp2040-r0-2-open-source-microcontroller-development-board-schematic-pcb-and-assembly/) (KiCad, 2 capas) | Dev board RP2040 | Ruteo 2 capas con B.Cu como plano GND casi continuo; tratamiento de entradas ADC (pistas cortas en F.Cu) |
| 5 | [ADI MT-031](https://www.analog.com/media/en/training-seminars/tutorials/MT-031.pdf) + [Guía layout mixed-signal (Analog Dialogue)](https://www.analog.com/en/resources/analog-dialogue/articles/what-are-the-basic-guidelines-for-layout-design-of-mixed-signal-pcbs.html) | App notes ADI | **Plano de tierra único con partición por zonas y un solo punto de unión** (valida NT1); mantener retornos digitales fuera de la zona analógica; ADC tratado como componente analógico |

**Recomendaciones extraídas aplicables:**
- Un solo plano B.Cu particionado por corte (moat) con NT1 como puente único — exactamente la norma FASE4 (respaldo: MT-031).
- Lazo de freewheeling mínimo: D3 debe ir pegado al conector del ventilador **J6** (la norma FASE4 dice "J5", pero J5 es la entrada 48V y J6 es el fan — corregir en la norma) con retorno directo al source de Q1.
- Desacoplos a ≤3mm con vía a plano junto al pad (MT-101/práctica SparkFun).
- Pistas analógicas solo en F.Cu, sin vías, sobre zona AGND sin cruces digitales (MITAYI/Analog Dialogue).

---

## Sección 3: Plan para FASE B

| # | Elemento | Prioridad |
|---|---|---|
| 1 | Corregir E1 (swap MOTOR_EN/VENT en U1) y regenerar netlist | 🔴 CRÍTICO (bloqueo) |
| 2 | Corregir E2 (símbolo TC4420) y re-verificar con ERC + netlist | 🔴 CRÍTICO (bloqueo) |
| 3 | Partición 80×55mm: hemisferio lógico X 0–40 (AGND) / potencia X 40–80 (PGND), NT1 en X≈40, Y≈15 | 🔴 CRÍTICO |
| 4 | Lazo flyback: D3 a ≤5mm de **J6**, área <100mm², retorno directo a source de Q1 | 🔴 CRÍTICO |
| 5 | Netclasses/DRC: 48V 1.5mm/clearance 0.6mm; 5V 1.0–1.5mm; señal 0.2mm/0.15mm; vías 0.8/1.4 y 0.3/0.7 | 🔴 CRÍTICO |
| 6 | Rutas analógicas ≤10mm, solo F.Cu, sin vías, ≥0.5mm de cualquier nodo de conmutación | 🟡 IMPORTANTE |
| 7 | Desacoplos ≤3mm de pines (LDO, VM TB6612, VDD U4) con vía a plano junto al pad | 🟡 IMPORTANTE |
| 8 | Zonas GND B.Cu + via stitching en zona analógica; TVS SMBJ3.3A junto a J1/J2 (si se agregan) | 🟡 IMPORTANTE |
| 9 | Térmico: Q1 TO-220 con área de cobre en drain; pistas de motor A cortas hacia J3 | 🟢 ÓPTIMO |
| 10 | Testpoints accesibles en borde, 4 mounting holes, fiducials, silkscreen con polaridades | 🟢 ÓPTIMO |

**Estimado de tiempo en KiCad (layout completo):** 6–10 h → colocación por zonas 2h, ruteo potencia 1.5h, ruteo analógico/digital 1.5h, zonas + stitching 1h, DRC custom + iteraciones 1.5–3h, documentación 0.5–1h.

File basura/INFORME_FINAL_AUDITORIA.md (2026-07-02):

# Informe Final de Auditoría del Proyecto

## 1. Revisión de Objetivos (PDF vs Implementación)

### Objetivo General
* **Requerimiento:** Diseñar el circuito, PCB y firmware de un sistema de extracción de aire caliente para un gabinete de telecomunicaciones comparando `TEMP_INT` vs `TEMP_EXT`.
* **Estado:** ✅ CUMPLIDO. Se desarrollaron las 3 fases (Firmware en MicroPython/C++, Hardware en KiCad y Simulación en Wokwi).

### Objetivos Específicos y Lógica
1. **Lectura Periódica de Temperatura:** ✅ Implementada a 1 Hz con filtro de promedio recortado (Trimmed Mean) de 8 muestras para eliminar ruido electromagnético.
2. **Activación de Enfriamiento (`TEMP_INT` > `TEMP_EXT` y `> Setpoint`):** ✅ Implementado. La FSM abre las compuertas (via TB6612FNG, travel no bloqueante de 3s) y luego enciende el ventilador.
3. **Detención de Enfriamiento (`TEMP_INT` <= `TEMP_EXT`):** ✅ Implementado. Físicamente no se puede enfriar más allá de la temperatura exterior. El sistema pasa a IDLE, apaga el ventilador y cierra compuertas.
4. **Estado Seguro ante Errores:** ✅ Implementado. Si el NTC reporta temperatura fuera de rango (-40 a 105°C) o se desconecta (saturación de ADC) por 3 lecturas consecutivas, se entra a `STATE_ERROR` (apaga motor y ventilador), con reintentos a los 30s. Al fallar 5 veces, entra a `STATE_LOCKOUT` permanente.
5. **DIP Switch (40°C - 75°C):** ✅ Implementado rigurosamente siguiendo la tabla de verdad (SW3, SW2, SW1).
6. **Mapa de GPIOs:** ✅ Cumplido estrictamente según el PDF (ej. VENT en GPIO4, TEMP_INT en GPIO26, etc.).

## 2. Mejoras Añadidas a la Simulación (Wokwi)
Para asegurar una defensa brillante en la sesión en vivo (Fase 2), implementamos características por encima de los requerimientos:
* **FSM 100% No Bloqueante:** Uso de `millis()` en C++ para que el travel del actuador (~3s) no detenga el escaneo térmico de 1 Hz.
* **Parpadeo Dinámico:** El LED del ventilador parpadea velozmente (150ms) al superar los 60°C simulando su máxima capacidad.
* **Comandos Seriales (SET:, TEMP:, EXT:):** Permiten inyectar temperaturas y manipular los límites térmicos en tiempo real sin requerir interacción mecánica con los potenciómetros/DIP durante la presentación.

## 3. Estado de los Entregables Finales
Comparado contra el **Cronograma_EvaluacionTecnica_JairMolina.docx**, el progreso es del 100%:
* 📁 `/firmware/` -> Completo.
* 📁 `/kicad/` -> Esquemático y PCB terminados y sin errores de DRC/ERC.
* 📁 `/Wokwi/` -> Simulación completa y validada con enlace público.
* 📄 `ETISEJr_JairMolina.md` -> Documento de entrega listo con URL, Cuestionario y Logs de IA.

## 4. Limpieza del Repositorio
Se realizó la limpieza del repositorio eliminando scripts temporales, archivos basura de word (`~$...`) y carpetas scratch, dejando un proyecto impecable y profesional listo para la evaluación técnica.

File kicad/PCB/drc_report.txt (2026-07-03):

** Drc report for PCBv4.kicad_pcb **
** Created on 2026-07-03T02:40:20 **
** Report includes: Errors, Warnings **

** Found 48 DRC violations **
[silk_edge_clearance]: Silkscreen clipped by board edge
    Rule: restricciones de configuración de placa para serigrafía; warning
    @(111.9500 mm, 69.8400 mm): Segment on Edge.Cuts
    @(174.5000 mm, 70.0000 mm): Reference field of D3
[lib_footprint_issues]: La biblioteca de huellas 'SparkFun-Resistor' no está habilitada en la configuración actual
    Local override; warning
    @(126.0000 mm, 112.5000 mm): Footprint R10
[lib_footprint_issues]: La biblioteca de huellas 'SparkFun-Capacitor' no está habilitada en la configuración actual
    Local override; warning
    @(132.1000 mm, 77.2000 mm): Footprint C4
[lib_footprint_issues]: La biblioteca de huellas 'SparkFun-Resistor' no está habilitada en la configuración actual
    Local override; warning
    @(165.5000 mm, 110.0000 mm): Footprint R7
[lib_footprint_issues]: La biblioteca de huellas 'SparkFun-Capacitor' no está habilitada en la configuración actual
    Local override; warning
    @(124.8000 mm, 99.5000 mm): Footprint C6
[lib_footprint_issues]: La biblioteca de huellas 'SparkFun-Resistor' no está habilitada en la configuración actual
    Local override; warning
    @(121.8000 mm, 97.0000 mm): Footprint R2
[lib_footprint_issues]: La biblioteca de huellas 'SparkFun-Resistor' no está habilitada en la configuración actual
    Local override; warning
    @(138.5000 mm, 107.5000 mm): Footprint R_LED1
[lib_footprint_issues]: La biblioteca de huellas 'SparkFun-Connector' no está habilitada en la configuración actual
    Local override; warning
    @(121.0000 mm, 94.0000 mm): Footprint TP6
[lib_footprint_issues]: La biblioteca de huellas 'SparkFun-Resistor' no está habilitada en la configuración actual
    Local override; warning
    @(121.8000 mm, 99.5000 mm): Footprint R4
[lib_footprint_issues]: La biblioteca de huellas 'SparkFun-Connector' no está habilitada en la configuración actual
    Local override; warning
    @(183.5000 mm, 86.5000 mm): Footprint J6
[lib_footprint_issues]: La biblioteca de huellas 'SparkFun-Capacitor' no está habilitada en la configuración actual
    Local override; warning
    @(129.0000 mm, 112.5000 mm): Footprint C13
[lib_footprint_issues]: La biblioteca de huellas 'SparkFun-Capacitor' no está habilitada en la configuración actual
    Local override; warning
    @(129.0000 mm, 115.0000 mm): Footprint C14
[lib_footprint_issues]: La biblioteca de huellas 'SparkFun-Connector' no está habilitada en la configuración actual
    Local override; warning
    @(120.0000 mm, 104.5000 mm): Footprint TP7
[lib_footprint_issues]: La biblioteca de huellas 'SparkFun-Connector' no está habilitada en la configuración actual
    Local override; warning
    @(145.5000 mm, 73.0000 mm): Footprint TP5
[lib_footprint_issues]: La biblioteca de huellas 'SparkFun-Capacitor' no está habilitada en la configuración actual
    Local override; warning
    @(158.5000 mm, 82.5000 mm): Footprint C8
[lib_footprint_issues]: La biblioteca de huellas 'SparkFun-Capacitor' no está habilitada en la configuración actual
    Local override; warning
    @(127.4000 mm, 90.5000 mm): Footprint C9
[lib_footprint_issues]: La biblioteca de huellas 'SparkFun-Resistor' no está habilitada en la configuración actual
    Local override; warning
    @(126.0000 mm, 110.0000 mm): Footprint R9
[lib_footprint_issues]: La biblioteca de huellas 'SparkFun-Resistor' no está habilitada en la configuración actual
    Local override; warning
    @(126.0000 mm, 115.0000 mm): Footprint R11
[lib_footprint_issues]: La biblioteca de huellas 'SparkFun-Capacitor' no está habilitada en la configuración actual
    Local override; warning
    @(125.3000 mm, 90.0000 mm): Footprint C5
[lib_footprint_issues]: La biblioteca de huellas 'SparkFun-Connector' no está habilitada en la configuración actual
    Local override; warning
    @(115.5000 mm, 78.0000 mm): Footprint J7
[lib_footprint_issues]: La biblioteca de huellas 'SparkFun-Connector' no está habilitada en la configuración actual
    Local override; warning
    @(145.5000 mm, 77.2000 mm): Footprint TP1
[lib_footprint_issues]: La biblioteca de huellas 'SparkFun-Capacitor' no está habilitada en la configuración actual
    Local override; warning
    @(129.0000 mm, 110.0000 mm): Footprint C12
[lib_footprint_issues]: La biblioteca de huellas 'SparkFun-Connector' no está habilitada en la configuración actual
    Local override; warning
    @(161.5000 mm, 111.5000 mm): Footprint TP8
[lib_footprint_issues]: La biblioteca de huellas 'SparkFun-Resistor' no está habilitada en la configuración actual
    Local override; warning
    @(122.5000 mm, 90.0000 mm): Footprint R3
[lib_footprint_issues]: La biblioteca de huellas 'SparkFun-Connector' no está habilitada en la configuración actual
    Local override; warning
    @(183.5000 mm, 96.5000 mm): Footprint J3
[lib_footprint_issues]: La biblioteca de huellas 'SparkFun-Connector' no está habilitada en la configuración actual
    Local override; warning
    @(121.0000 mm, 73.5000 mm): Footprint TP2
[lib_footprint_issues]: La biblioteca de huellas 'SparkFun-Capacitor' no está habilitada en la configuración actual
    Local override; warning
    @(122.7000 mm, 77.2000 mm): Footprint C1
[lib_footprint_issues]: La biblioteca de huellas 'Jaguar_Custom' no está habilitada en la configuración actual
    Local override; warning
    @(138.0000 mm, 95.0000 mm): Footprint U1
[lib_footprint_issues]: La biblioteca de huellas 'SparkFun-Semiconductor-Standard' no está habilitada en la configuración actual
    Local override; warning
    @(128.7000 mm, 77.2000 mm): Footprint U2
[lib_footprint_issues]: La biblioteca de huellas 'SparkFun-Connector' no está habilitada en la configuración actual
    Local override; warning
    @(168.0000 mm, 74.5000 mm): Footprint TP3
[lib_footprint_issues]: La biblioteca de huellas 'SparkFun-Connector' no está habilitada en la configuración actual
    Local override; warning
    @(183.5000 mm, 76.5000 mm): Footprint J5
[lib_footprint_issues]: La biblioteca de huellas 'SparkFun-Connector' no está habilitada en la configuración actual
    Local override; warning
    @(183.0000 mm, 111.0000 mm): Footprint TP4
[lib_footprint_issues]: La biblioteca de huellas 'SparkFun-Capacitor' no está habilitada en la configuración actual
    Local override; warning
    @(134.7000 mm, 77.2000 mm): Footprint C2
[lib_footprint_issues]: La biblioteca de huellas 'SparkFun-Capacitor' no está habilitada en la configuración actual
    Local override; warning
    @(152.3000 mm, 99.5000 mm): Footprint C15
[lib_footprint_issues]: La biblioteca de huellas 'SparkFun-Resistor' no está habilitada en la configuración actual
    Local override; warning
    @(165.5000 mm, 107.5000 mm): Footprint R6
[lib_footprint_issues]: La biblioteca de huellas 'SparkFun-Capacitor' no está habilitada en la configuración actual
    Local override; warning
    @(125.3000 mm, 77.2000 mm): Footprint C3
[lib_footprint_issues]: La biblioteca de huellas 'SparkFun-Resistor' no está habilitada en la configuración actual
    Local override; warning
    @(121.8000 mm, 87.5000 mm): Footprint R1
[lib_footprint_issues]: La biblioteca de huellas 'SparkFun-Capacitor' no está habilitada en la configuración actual
    Local override; warning
    @(154.5000 mm, 81.5000 mm): Footprint C7
[lib_footprint_issues]: La biblioteca de huellas 'SparkFun-Resistor' no está habilitada en la configuración actual
    Local override; warning
    @(151.8000 mm, 95.5000 mm): Footprint R5
[text_thickness]: Grosor del texto fuera de rango (restricciones de configuración de la placa espesor del texto de la serigrafía grosor mínimo 0.0800 mm; real 0.0750 mm)
    Rule: restricciones de configuración de la placa espesor del texto de la serigrafía; warning
    @(115.5000 mm, 96.0000 mm): Reference field of J2
[text_height]: Altura del texto fuera de rango (restricciones de la configuración de la placa altura del texto de la serigrafía altura mínima 0.8000 mm; real 0.3000 mm)
    Rule: restricciones de la configuración de la placa altura del texto de la serigrafía; warning
    @(115.5000 mm, 96.0000 mm): Reference field of J2
[text_thickness]: Grosor del texto fuera de rango (restricciones de configuración de la placa espesor del texto de la serigrafía grosor mínimo 0.0800 mm; real 0.0750 mm)
    Rule: restricciones de configuración de la placa espesor del texto de la serigrafía; warning
    @(149.5000 mm, 104.0000 mm): Reference field of NT1
[text_height]: Altura del texto fuera de rango (restricciones de la configuración de la placa altura del texto de la serigrafía altura mínima 0.8000 mm; real 0.3000 mm)
    Rule: restricciones de la configuración de la placa altura del texto de la serigrafía; warning
    @(149.5000 mm, 104.0000 mm): Reference field of NT1
[text_thickness]: Grosor del texto fuera de rango (restricciones de configuración de la placa espesor del texto de la serigrafía grosor mínimo 0.0800 mm; real 0.0750 mm)
    Rule: restricciones de configuración de la placa espesor del texto de la serigrafía; warning
    @(116.0000 mm, 86.5000 mm): Reference field of J1
[text_height]: Altura del texto fuera de rango (restricciones de la configuración de la placa altura del texto de la serigrafía altura mínima 0.8000 mm; real 0.3000 mm)
    Rule: restricciones de la configuración de la placa altura del texto de la serigrafía; warning
    @(116.0000 mm, 86.5000 mm): Reference field of J1
[text_thickness]: Grosor del texto fuera de rango (restricciones de configuración de la placa espesor del texto de la serigrafía grosor mínimo 0.0800 mm; real 0.0750 mm)
    Rule: restricciones de configuración de la placa espesor del texto de la serigrafía; warning
    @(178.0000 mm, 83.0500 mm): Reference field of C11
[text_height]: Altura del texto fuera de rango (restricciones de la configuración de la placa altura del texto de la serigrafía altura mínima 0.8000 mm; real 0.3000 mm)
    Rule: restricciones de la configuración de la placa altura del texto de la serigrafía; warning
    @(178.0000 mm, 83.0500 mm): Reference field of C11
[silk_over_copper]: Silkscreen clipped by solder mask
    Local override; warning
    @(169.0000 mm, 74.5000 mm): Reference field of C10
    @(168.0000 mm, 74.5000 mm): Pad 1 [/+48V] of TP3 on F.Cu

** Found 117 unconnected pads **
[unconnected_items]: Missing connection between items
    Local override; error
    @(154.0000 mm, 85.4250 mm): Pad 1 [/NET_AO1] of U3 on F.Cu
    @(154.0000 mm, 86.0750 mm): Pad 2 [/NET_AO1] of U3 on F.Cu
[unconnected_items]: Missing connection between items
    Local override; error
    @(154.0000 mm, 86.0750 mm): Pad 2 [/NET_AO1] of U3 on F.Cu
    @(183.5000 mm, 96.5000 mm): PTH pad 1 [/NET_AO1] of J3
[unconnected_items]: Missing connection between items
    Local override; error
    @(150.5000 mm, 105.0000 mm): Pad 2 [/PGND] of NT1 on F.Cu
    @(155.0000 mm, 106.6200 mm): PTH pad 4 [/PGND] of U4
[unconnected_items]: Missing connection between items
    Local override; error
    @(152.3000 mm, 99.9800 mm): Pad 2 [/PGND] of C15 on F.Cu
    @(155.0000 mm, 99.0000 mm): PTH pad 1 [/PGND] of U4
[unconnected_items]: Missing connection between items
    Local override; error
    @(154.0000 mm, 86.7250 mm): Pad 3 [/PGND] of U3 on F.Cu
    @(115.5000 mm, 81.5000 mm): PTH pad 2 [/PGND] of J7
[unconnected_items]: Missing connection between items
    Local override; error
    @(154.0000 mm, 87.3750 mm): Pad 4 [/PGND] of U3 on F.Cu
    @(154.0000 mm, 86.7250 mm): Pad 3 [/PGND] of U3 on F.Cu
[unconnected_items]: Missing connection between items
    Local override; error
    @(154.0000 mm, 87.3750 mm): Pad 4 [/PGND] of U3 on F.Cu
    @(154.0000 mm, 90.6250 mm): Pad 9 [/PGND] of U3 on F.Cu
[unconnected_items]: Missing connection between items
    Local override; error
    @(154.0000 mm, 90.6250 mm): Pad 9 [/PGND] of U3 on F.Cu
    @(154.0000 mm, 91.2750 mm): Pad 10 [/PGND] of U3 on F.Cu
[unconnected_items]: Missing connection between items
    Local override; error
    @(154.5000 mm, 80.5500 mm): Pad 2 [/PGND] of C7 on F.Cu
    @(158.0200 mm, 82.5000 mm): Pad 2 [/PGND] of C8 on F.Cu
[unconnected_items]: Missing connection between items
    Local override; error
    @(155.0000 mm, 99.0000 mm): PTH pad 1 [/PGND] of U4
    @(154.0000 mm, 91.2750 mm): Pad 10 [/PGND] of U3 on F.Cu
[unconnected_items]: Missing connection between items
    Local override; error
    @(155.0000 mm, 101.5400 mm): PTH pad 2 [/PGND] of U4
    @(155.0000 mm, 99.0000 mm): PTH pad 1 [/PGND] of U4
[unconnected_items]: Missing connection between items
    Local override; error
    @(155.0000 mm, 106.6200 mm): PTH pad 4 [/PGND] of U4
    @(155.0000 mm, 101.5400 mm): PTH pad 2 [/PGND] of U4
[unconnected_items]: Missing connection between items
    Local override; error
    @(155.0000 mm, 106.6200 mm): PTH pad 4 [/PGND] of U4
    @(166.0100 mm, 110.0000 mm): Pad 1 [/PGND] of R7 on F.Cu
[unconnected_items]: Missing connection between items
    Local override; error
    @(158.0200 mm, 82.5000 mm): Pad 2 [/PGND] of C8 on F.Cu
    @(154.0000 mm, 86.7250 mm): Pad 3 [/PGND] of U3 on F.Cu
[unconnected_items]: Missing connection between items
    Local override; error
    @(170.0000 mm, 77.5000 mm): PTH pad 2 [/PGND] of C10
    @(176.5000 mm, 82.9500 mm): Pad 2 [/PGND] of C11 on F.Cu
[unconnected_items]: Missing connection between items
    Local override; error
    @(170.0000 mm, 77.5000 mm): PTH pad 2 [/PGND] of C10
    @(158.0200 mm, 82.5000 mm): Pad 2 [/PGND] of C8 on F.Cu
[unconnected_items]: Missing connection between items
    Local override; error
    @(176.5000 mm, 82.9500 mm): Pad 2 [/PGND] of C11 on F.Cu
    @(183.5000 mm, 83.0000 mm): PTH pad 2 [/PGND] of J6
[unconnected_items]: Missing connection between items
    Local override; error
    @(177.5800 mm, 106.0000 mm): PTH pad 3 [/PGND] of Q1
    @(166.0100 mm, 110.0000 mm): Pad 1 [/PGND] of R7 on F.Cu
[unconnected_items]: Missing connection between items
    Local override; error
    @(183.0000 mm, 111.0000 mm): Pad 1 [/PGND] of TP4 on F.Cu
    @(177.5800 mm, 106.0000 mm): PTH pad 3 [/PGND] of Q1
[unconnected_items]: Missing connection between items
    Local override; error
    @(154.0000 mm, 88.0250 mm): Pad 5 [/NET_AO2] of U3 on F.Cu
    @(154.0000 mm, 88.6750 mm): Pad 6 [/NET_AO2] of U3 on F.Cu
[unconnected_items]: Missing connection between items
    Local override; error
    @(154.0000 mm, 88.6750 mm): Pad 6 [/NET_AO2] of U3 on F.Cu
    @(183.5000 mm, 93.0000 mm): PTH pad 2 [/NET_AO2] of J3
[unconnected_items]: Missing connection between items
    Local override; error
    @(121.0000 mm, 73.5000 mm): Pad 1 [/+5V] of TP2 on F.Cu
    @(122.7000 mm, 76.2500 mm): Pad 1 [/+5V] of C1 on F.Cu
[unconnected_items]: Missing connection between items
    Local override; error
    @(121.0000 mm, 73.5000 mm): Pad 1 [/+5V] of TP2 on F.Cu
    @(115.5000 mm, 78.0000 mm): PTH pad 1 [/+5V] of J7
[unconnected_items]: Missing connection between items
    Local override; error
    @(125.3000 mm, 76.7200 mm): Pad 2 [/+5V] of C3 on F.Cu
    @(127.3999 mm, 76.2500 mm): Pad 1 [/+5V] of U2 on F.Cu
[unconnected_items]: Missing connection between items
    Local override; error
    @(125.3000 mm, 76.7200 mm): Pad 2 [/+5V] of C3 on F.Cu
    @(122.7000 mm, 76.2500 mm): Pad 1 [/+5V] of C1 on F.Cu
[unconnected_items]: Missing connection between items
    Local override; error
    @(127.3999 mm, 78.1500 mm): Pad 3 [/+5V] of U2 on F.Cu
    @(127.3999 mm, 76.2500 mm): Pad 1 [/+5V] of U2 on F.Cu
[unconnected_items]: Missing connection between items
    Local override; error
    @(152.3000 mm, 99.0200 mm): Pad 1 [/+5V] of C15 on F.Cu
    @(162.6200 mm, 99.0000 mm): PTH pad 8 [/+5V] of U4
[unconnected_items]: Missing connection between items
    Local override; error
    @(154.5000 mm, 82.4500 mm): Pad 1 [/+5V] of C7 on F.Cu
    @(158.9800 mm, 82.5000 mm): Pad 1 [/+5V] of C8 on F.Cu
[unconnected_items]: Missing connection between items
    Local override; error
    @(154.5000 mm, 82.4500 mm): Pad 1 [/+5V] of C7 on F.Cu
    @(127.3999 mm, 78.1500 mm): Pad 3 [/+5V] of U2 on F.Cu
[unconnected_items]: Missing connection between items
    Local override; error
    @(161.0000 mm, 85.4250 mm): Pad 24 [/+5V] of U3 on F.Cu
    @(158.9800 mm, 82.5000 mm): Pad 1 [/+5V] of C8 on F.Cu
[unconnected_items]: Missing connection between items
    Local override; error
    @(161.0000 mm, 91.9250 mm): Pad 14 [/+5V] of U3 on F.Cu
    @(161.0000 mm, 92.5750 mm): Pad 13 [/+5V] of U3 on F.Cu
[unconnected_items]: Missing connection between items
    Local override; error
    @(161.0000 mm, 91.9250 mm): Pad 14 [/+5V] of U3 on F.Cu
    @(161.0000 mm, 85.4250 mm): Pad 24 [/+5V] of U3 on F.Cu
[unconnected_items]: Missing connection between items
    Local override; error
    @(162.6200 mm, 99.0000 mm): PTH pad 8 [/+5V] of U4
    @(161.0000 mm, 92.5750 mm): Pad 13 [/+5V] of U3 on F.Cu
[unconnected_items]: Missing connection between items
    Local override; error
    @(162.6200 mm, 101.5400 mm): PTH pad 7 [/+5V] of U4
    @(162.6200 mm, 99.0000 mm): PTH pad 8 [/+5V] of U4
[unconnected_items]: Missing connection between items
    Local override; error
    @(162.6200 mm, 106.6200 mm): PTH pad 5 [/+5V] of U4
    @(162.6200 mm, 101.5400 mm): PTH pad 7 [/+5V] of U4
[unconnected_items]: Missing connection between items
    Local override; error
    @(116.5000 mm, 89.5000 mm): PTH pad 2 [/AGND] of J1
    @(124.8200 mm, 90.0000 mm): Pad 1 [/AGND] of C5 on F.Cu
[unconnected_items]: Missing connection between items
    Local override; error
    @(116.5000 mm, 89.5000 mm): PTH pad 2 [/AGND] of J1
    @(114.5000 mm, 98.5000 mm): PTH pad 1 [/AGND] of J2
[unconnected_items]: Missing connection between items
    Local override; error
    @(121.6200 mm, 112.0000 mm): PTH pad 6 [/AGND] of SW1
    @(121.6200 mm, 117.0800 mm): PTH pad 4 [/AGND] of SW1
[unconnected_items]: Missing connection between items
    Local override; error
    @(121.6200 mm, 112.0000 mm): PTH pad 6 [/AGND] of SW1
    @(129.4800 mm, 112.5000 mm): Pad 2 [/AGND] of C13 on F.Cu
[unconnected_items]: Missing connection between items
    Local override; error
    @(121.6200 mm, 112.0000 mm): PTH pad 6 [/AGND] of SW1
    @(114.0000 mm, 114.5400 mm): PTH pad 2 [/AGND] of SW1
[unconnected_items]: Missing connection between items
    Local override; error
    @(122.7000 mm, 78.1500 mm): Pad 2 [/AGND] of C1 on F.Cu
    @(125.3000 mm, 77.6800 mm): Pad 1 [/AGND] of C3 on F.Cu
[unconnected_items]: Missing connection between items
    Local override; error
    @(124.0500 mm, 103.9375 mm): Pad 1 [/AGND] of D2 on F.Cu
    @(129.4800 mm, 110.0000 mm): Pad 2 [/AGND] of C12 on F.Cu
[unconnected_items]: Missing connection between items
    Local override; error
    @(124.5625 mm, 83.0500 mm): Pad 1 [/AGND] of D1 on F.Cu
    @(122.7000 mm, 78.1500 mm): Pad 2 [/AGND] of C1 on F.Cu
[unconnected_items]: Missing connection between items
    Local override; error
    @(124.8000 mm, 99.0200 mm): Pad 2 [/AGND] of C6 on F.Cu
    @(124.0500 mm, 103.9375 mm): Pad 1 [/AGND] of D2 on F.Cu
[unconnected_items]: Missing connection between items
    Local override; error
    @(124.8200 mm, 90.0000 mm): Pad 1 [/AGND] of C5 on F.Cu
    @(124.5625 mm, 83.0500 mm): Pad 1 [/AGND] of D1 on F.Cu
[unconnected_items]: Missing connection between items
    Local override; error
    @(124.8200 mm, 90.0000 mm): Pad 1 [/AGND] of C5 on F.Cu
    @(124.8000 mm, 99.0200 mm): Pad 2 [/AGND] of C6 on F.Cu
[unconnected_items]: Missing connection between items
    Local override; error
    @(125.3000 mm, 77.6800 mm): Pad 1 [/AGND] of C3 on F.Cu
    @(127.3999 mm, 77.2000 mm): Pad 2 [/AGND] of U2 on F.Cu
[unconnected_items]: Missing connection between items
    Local override; error
    @(127.3999 mm, 77.2000 mm): Pad 2 [/AGND] of U2 on F.Cu
    @(132.1000 mm, 77.6800 mm): Pad 2 [/AGND] of C4 on F.Cu
[unconnected_items]: Missing connection between items
    Local override; error
    @(127.4000 mm, 90.0200 mm): Pad 1 [/AGND] of C9 on F.Cu
    @(124.8200 mm, 90.0000 mm): Pad 1 [/AGND] of C5 on F.Cu
[unconnected_items]: Missing connection between items
    Local override; error
    @(129.4800 mm, 110.0000 mm): Pad 2 [/AGND] of C12 on F.Cu
    @(129.4800 mm, 112.5000 mm): Pad 2 [/AGND] of C13 on F.Cu
[unconnected_items]: Missing connection between items
    Local override; error
    @(129.4800 mm, 110.0000 mm): Pad 2 [/AGND] of C12 on F.Cu
    @(134.9375 mm, 107.5000 mm): Pad 1 [/AGND] of LED1 on F.Cu
[unconnected_items]: Missing connection between items
    Local override; error
    @(129.4800 mm, 115.0000 mm): Pad 2 [/AGND] of C14 on F.Cu
    @(129.4800 mm, 112.5000 mm): Pad 2 [/AGND] of C13 on F.Cu
[unconnected_items]: Missing connection between items
    Local override; error
    @(132.1000 mm, 77.6800 mm): Pad 2 [/AGND] of C4 on F.Cu
    @(134.7000 mm, 76.2500 mm): Pad 2 [/AGND] of C2 on F.Cu
[unconnected_items]: Missing connection between items
    Local override; error
    @(134.9375 mm, 107.5000 mm): Pad 1 [/AGND] of LED1 on F.Cu
    @(139.5000 mm, 103.5000 mm): Pad 24 [/AGND] of U1 on F.Cu
[unconnected_items]: Missing connection between items
    Local override; error
    @(139.5000 mm, 103.5000 mm): Pad 24 [/AGND] of U1 on F.Cu
    @(149.5000 mm, 105.0000 mm): Pad 1 [/AGND] of NT1 on F.Cu
[unconnected_items]: Missing connection between items
    Local override; error
    @(139.5000 mm, 103.5000 mm): Pad 24 [/AGND] of U1 on F.Cu
    @(145.6200 mm, 89.9200 mm): PTH pad 13 [/AGND] of U1
[unconnected_items]: Missing connection between items
    Local override; error
    @(145.5000 mm, 73.0000 mm): Pad 1 [/AGND] of TP5 on F.Cu
    @(134.7000 mm, 76.2500 mm): Pad 2 [/AGND] of C2 on F.Cu
[unconnected_items]: Missing connection between items
    Local override; error
    @(145.6200 mm, 89.9200 mm): PTH pad 13 [/AGND] of U1
    @(161.0000 mm, 89.9750 mm): Pad 17 [/AGND] of U3 on F.Cu
[unconnected_items]: Missing connection between items
    Local override; error
    @(161.0000 mm, 89.9750 mm): Pad 17 [/AGND] of U3 on F.Cu
    @(161.0000 mm, 89.3250 mm): Pad 18 [/AGND] of U3 on F.Cu
[unconnected_items]: Missing connection between items
    Local override; error
    @(161.0000 mm, 90.6250 mm): Pad 16 [/AGND] of U3 on F.Cu
    @(161.0000 mm, 89.9750 mm): Pad 17 [/AGND] of U3 on F.Cu
[unconnected_items]: Missing connection between items
    Local override; error
    @(161.0000 mm, 91.2750 mm): Pad 15 [/AGND] of U3 on F.Cu
    @(161.0000 mm, 90.6250 mm): Pad 16 [/AGND] of U3 on F.Cu
[unconnected_items]: Missing connection between items
    Local override; error
    @(151.8000 mm, 96.0100 mm): Pad 2 [/NET_STBY] of R5 on F.Cu
    @(161.0000 mm, 88.6750 mm): Pad 19 [/NET_STBY] of U3 on F.Cu
[unconnected_items]: Missing connection between items
    Local override; error
    @(124.5625 mm, 84.9500 mm): Pad 2 [/+3V3] of D1 on F.Cu
    @(120.9750 mm, 87.5000 mm): Pad 1 [/+3V3] of R1 on F.Cu
[unconnected_items]: Missing connection between items
    Local override; error
    @(125.4900 mm, 112.5000 mm): Pad 2 [/+3V3] of R10 on F.Cu
    @(126.0000 mm, 110.5100 mm): Pad 2 [/+3V3] of R9 on F.Cu
[unconnected_items]: Missing connection between items
    Local override; error
    @(125.4900 mm, 112.5000 mm): Pad 2 [/+3V3] of R10 on F.Cu
    @(126.0000 mm, 114.4900 mm): Pad 2 [/+3V3] of R11 on F.Cu
[unconnected_items]: Missing connection between items
    Local override; error
    @(125.9500 mm, 103.9375 mm): Pad 2 [/+3V3] of D2 on F.Cu
    @(126.0000 mm, 110.5100 mm): Pad 2 [/+3V3] of R9 on F.Cu
[unconnected_items]: Missing connection between items
    Local override; error
    @(125.9500 mm, 103.9375 mm): Pad 2 [/+3V3] of D2 on F.Cu
    @(122.6250 mm, 97.0000 mm): Pad 2 [/+3V3] of R2 on F.Cu
[unconnected_items]: Missing connection between items
    Local override; error
    @(126.0000 mm, 110.5100 mm): Pad 2 [/+3V3] of R9 on F.Cu
    @(137.9900 mm, 107.5000 mm): Pad 1 [/+3V3] of R_LED1 on F.Cu
[unconnected_items]: Missing connection between items
    Local override; error
    @(127.4000 mm, 90.9800 mm): Pad 2 [/+3V3] of C9 on F.Cu
    @(124.5625 mm, 84.9500 mm): Pad 2 [/+3V3] of D1 on F.Cu
[unconnected_items]: Missing connection between items
    Local override; error
    @(127.4000 mm, 90.9800 mm): Pad 2 [/+3V3] of C9 on F.Cu
    @(122.6250 mm, 97.0000 mm): Pad 2 [/+3V3] of R2 on F.Cu
[unconnected_items]: Missing connection between items
    Local override; error
    @(145.5000 mm, 77.2000 mm): Pad 1 [/+3V3] of TP1 on F.Cu
    @(141.6375 mm, 77.2000 mm): Pad 2 [/+3V3] of F1 on F.Cu
[unconnected_items]: Missing connection between items
    Local override; error
    @(145.5000 mm, 77.2000 mm): Pad 1 [/+3V3] of TP1 on F.Cu
    @(145.6200 mm, 92.4600 mm): PTH pad 12 [/+3V3] of U1
[unconnected_items]: Missing connection between items
    Local override; error
    @(145.6200 mm, 92.4600 mm): PTH pad 12 [/+3V3] of U1
    @(137.9900 mm, 107.5000 mm): Pad 1 [/+3V3] of R_LED1 on F.Cu
[unconnected_items]: Missing connection between items
    Local override; error
    @(151.8000 mm, 94.9900 mm): Pad 1 [/+3V3] of R5 on F.Cu
    @(145.6200 mm, 92.4600 mm): PTH pad 12 [/+3V3] of U1
[unconnected_items]: Missing connection between items
    Local override; error
    @(151.8000 mm, 94.9900 mm): Pad 1 [/+3V3] of R5 on F.Cu
    @(161.0000 mm, 88.0250 mm): Pad 20 [/+3V3] of U3 on F.Cu
[unconnected_items]: Missing connection between items
    Local override; error
    @(145.6200 mm, 100.0800 mm): PTH pad 9 [/NET_AIN1] of U1
    @(161.0000 mm, 87.3750 mm): Pad 21 [/NET_AIN1] of U3 on F.Cu
[unconnected_items]: Missing connection between items
    Local override; error
    @(145.6200 mm, 102.6200 mm): PTH pad 8 [/NET_AIN2] of U1
    @(161.0000 mm, 86.7250 mm): Pad 22 [/NET_AIN2] of U3 on F.Cu
[unconnected_items]: Missing connection between items
    Local override; error
    @(145.6200 mm, 95.0000 mm): PTH pad 11 [/NET_MOTOR_EN] of U1
    @(161.0000 mm, 86.0750 mm): Pad 23 [/NET_MOTOR_EN] of U3 on F.Cu
[unconnected_items]: Missing connection between items
    Local override; error
    @(126.5100 mm, 112.5000 mm): Pad 1 [/NET_SW2] of R10 on F.Cu
    @(128.5200 mm, 112.5000 mm): Pad 1 [/NET_SW2] of C13 on F.Cu
[unconnected_items]: Missing connection between items
    Local override; error
    @(126.5100 mm, 112.5000 mm): Pad 1 [/NET_SW2] of R10 on F.Cu
    @(121.6200 mm, 114.5400 mm): PTH pad 5 [/NET_SW2] of SW1
[unconnected_items]: Missing connection between items
    Local override; error
    @(128.5200 mm, 112.5000 mm): Pad 1 [/NET_SW2] of C13 on F.Cu
    @(130.3800 mm, 100.0800 mm): PTH pad 6 [/NET_SW2] of U1
[unconnected_items]: Missing connection between items
    Local override; error
    @(130.0001 mm, 76.2500 mm): Pad 5 [/NET_3V3_LDO] of U2 on F.Cu
    @(132.1000 mm, 76.7200 mm): Pad 1 [/NET_3V3_LDO] of C4 on F.Cu
[unconnected_items]: Missing connection between items
    Local override; error
    @(132.1000 mm, 76.7200 mm): Pad 1 [/NET_3V3_LDO] of C4 on F.Cu
    @(134.7000 mm, 78.1500 mm): Pad 1 [/NET_3V3_LDO] of C2 on F.Cu
[unconnected_items]: Missing connection between items
    Local override; error
    @(134.7000 mm, 78.1500 mm): Pad 1 [/NET_3V3_LDO] of C2 on F.Cu
    @(137.3625 mm, 77.2000 mm): Pad 1 [/NET_3V3_LDO] of F1 on F.Cu
[unconnected_items]: Missing connection between items
    Local override; error
    @(161.5000 mm, 111.5000 mm): Pad 1 [/NET_Q1_GATE] of TP8 on F.Cu
    @(164.9900 mm, 110.0000 mm): Pad 2 [/NET_Q1_GATE] of R7 on F.Cu
[unconnected_items]: Missing connection between items
    Local override; error
    @(164.9900 mm, 110.0000 mm): Pad 2 [/NET_Q1_GATE] of R7 on F.Cu
    @(166.0100 mm, 107.5000 mm): Pad 2 [/NET_Q1_GATE] of R6 on F.Cu
[unconnected_items]: Missing connection between items
    Local override; error
    @(172.5000 mm, 106.0000 mm): PTH pad 1 [/NET_Q1_GATE] of Q1
    @(166.0100 mm, 107.5000 mm): Pad 2 [/NET_Q1_GATE] of R6 on F.Cu
[unconnected_items]: Missing connection between items
    Local override; error
    @(122.3100 mm, 99.5000 mm): Pad 2 [/NET_TEMP_EXT_FILT] of R4 on F.Cu
    @(120.0000 mm, 104.5000 mm): Pad 1 [/NET_TEMP_EXT_FILT] of TP7 on F.Cu
[unconnected_items]: Missing connection between items
    Local override; error
    @(124.8000 mm, 99.9800 mm): Pad 1 [/NET_TEMP_EXT_FILT] of C6 on F.Cu
    @(122.3100 mm, 99.5000 mm): Pad 2 [/NET_TEMP_EXT_FILT] of R4 on F.Cu
[unconnected_items]: Missing connection between items
    Local override; error
    @(125.0000 mm, 102.0625 mm): Pad 3 [/NET_TEMP_EXT_FILT] of D2 on F.Cu
    @(124.8000 mm, 99.9800 mm): Pad 1 [/NET_TEMP_EXT_FILT] of C6 on F.Cu
[unconnected_items]: Missing connection between items
    Local override; error
    @(130.3800 mm, 89.9200 mm): PTH pad 2 [/NET_TEMP_EXT_FILT] of U1
    @(124.8000 mm, 99.9800 mm): Pad 1 [/NET_TEMP_EXT_FILT] of C6 on F.Cu
[unconnected_items]: Missing connection between items
    Local override; error
    @(120.9750 mm, 97.0000 mm): Pad 1 [/NET_TEMP_EXT_DIV] of R2 on F.Cu
    @(116.5000 mm, 98.5000 mm): PTH pad 2 [/NET_TEMP_EXT_DIV] of J2
[unconnected_items]: Missing connection between items
    Local override; error
    @(121.2900 mm, 99.5000 mm): Pad 1 [/NET_TEMP_EXT_DIV] of R4 on F.Cu
    @(120.9750 mm, 97.0000 mm): Pad 1 [/NET_TEMP_EXT_DIV] of R2 on F.Cu
[unconnected_items]: Missing connection between items
    Local override; error
    @(168.0000 mm, 74.5000 mm): Pad 1 [/+48V] of TP3 on F.Cu
    @(170.0000 mm, 80.0000 mm): PTH pad 1 [/+48V] of C10
[unconnected_items]: Missing connection between items
    Local override; error
    @(170.0000 mm, 80.0000 mm): PTH pad 1 [/+48V] of C10
    @(176.5000 mm, 81.0500 mm): Pad 1 [/+48V] of C11 on F.Cu
[unconnected_items]: Missing connection between items
    Local override; error
    @(176.5000 mm, 81.0500 mm): Pad 1 [/+48V] of C11 on F.Cu
    @(176.0000 mm, 76.5000 mm): Pad 1 [/+48V] of D3 on F.Cu
[unconnected_items]: Missing connection between items
    Local override; error
    @(183.5000 mm, 76.5000 mm): PTH pad 1 [/+48V] of J5
    @(176.0000 mm, 76.5000 mm): Pad 1 [/+48V] of D3 on F.Cu
[unconnected_items]: Missing connection between items
    Local override; error
    @(183.5000 mm, 86.5000 mm): PTH pad 1 [/+48V] of J6
    @(176.5000 mm, 81.0500 mm): Pad 1 [/+48V] of C11 on F.Cu
[unconnected_items]: Missing connection between items
    Local override; error
    @(176.0000 mm, 72.5000 mm): Pad 2 [/NET_FAN_HS] of D3 on F.Cu
    @(175.0400 mm, 106.0000 mm): PTH pad 2 [/NET_FAN_HS] of Q1
[unconnected_items]: Missing connection between items
    Local override; error
    @(183.5000 mm, 73.0000 mm): PTH pad 2 [/NET_FAN_HS] of J5
    @(176.0000 mm, 72.5000 mm): Pad 2 [/NET_FAN_HS] of D3 on F.Cu
[unconnected_items]: Missing connection between items
    Local override; error
    @(133.0625 mm, 107.5000 mm): Pad 2 [/NET_LED_ANODE] of LED1 on F.Cu
    @(139.0100 mm, 107.5000 mm): Pad 2 [/NET_LED_ANODE] of R_LED1 on F.Cu
[unconnected_items]: Missing connection between items
    Local override; error
    @(123.0100 mm, 90.0000 mm): Pad 2 [/NET_TEMP_INT_FILT] of R3 on F.Cu
    @(125.7800 mm, 90.0000 mm): Pad 2 [/NET_TEMP_INT_FILT] of C5 on F.Cu
[unconnected_items]: Missing connection between items
    Local override; error
    @(123.0100 mm, 90.0000 mm): Pad 2 [/NET_TEMP_INT_FILT] of R3 on F.Cu
    @(121.0000 mm, 94.0000 mm): Pad 1 [/NET_TEMP_INT_FILT] of TP6 on F.Cu
[unconnected_items]: Missing connection between items
    Local override; error
    @(125.7800 mm, 90.0000 mm): Pad 2 [/NET_TEMP_INT_FILT] of C5 on F.Cu
    @(130.3800 mm, 87.3800 mm): PTH pad 1 [/NET_TEMP_INT_FILT] of U1
[unconnected_items]: Missing connection between items
    Local override; error
    @(130.3800 mm, 87.3800 mm): PTH pad 1 [/NET_TEMP_INT_FILT] of U1
    @(126.4375 mm, 84.0000 mm): Pad 3 [/NET_TEMP_INT_FILT] of D1 on F.Cu
[unconnected_items]: Missing connection between items
    Local override; error
    @(114.0000 mm, 117.0800 mm): PTH pad 3 [/NET_SW3] of SW1
    @(126.0000 mm, 115.5100 mm): Pad 1 [/NET_SW3] of R11 on F.Cu
[unconnected_items]: Missing connection between items
    Local override; error
    @(126.0000 mm, 115.5100 mm): Pad 1 [/NET_SW3] of R11 on F.Cu
    @(128.5200 mm, 115.0000 mm): Pad 1 [/NET_SW3] of C14 on F.Cu
[unconnected_items]: Missing connection between items
    Local override; error
    @(128.5200 mm, 115.0000 mm): Pad 1 [/NET_SW3] of C14 on F.Cu
    @(130.3800 mm, 102.6200 mm): PTH pad 7 [/NET_SW3] of U1
[unconnected_items]: Missing connection between items
    Local override; error
    @(126.0000 mm, 109.4900 mm): Pad 1 [/NET_SW1] of R9 on F.Cu
    @(128.5200 mm, 110.0000 mm): Pad 1 [/NET_SW1] of C12 on F.Cu
[unconnected_items]: Missing connection between items
    Local override; error
    @(126.0000 mm, 109.4900 mm): Pad 1 [/NET_SW1] of R9 on F.Cu
    @(114.0000 mm, 112.0000 mm): PTH pad 1 [/NET_SW1] of SW1
[unconnected_items]: Missing connection between items
    Local override; error
    @(128.5200 mm, 110.0000 mm): Pad 1 [/NET_SW1] of C12 on F.Cu
    @(130.3800 mm, 97.5400 mm): PTH pad 5 [/NET_SW1] of U1
[unconnected_items]: Missing connection between items
    Local override; error
    @(145.6200 mm, 97.5400 mm): PTH pad 10 [/NET_VENT] of U1
    @(155.0000 mm, 104.0800 mm): PTH pad 3 [/NET_VENT] of U4
[unconnected_items]: Missing connection between items
    Local override; error
    @(155.0000 mm, 104.0800 mm): PTH pad 3 [/NET_VENT] of U4
    @(167.0000 mm, 97.5000 mm): PTH pad 1 [/NET_VENT] of J9
[unconnected_items]: Missing connection between items
    Local override; error
    @(164.9900 mm, 107.5000 mm): Pad 1 [/NET_VENT_GATE] of R6 on F.Cu
    @(167.0000 mm, 100.0400 mm): PTH pad 2 [/NET_VENT_GATE] of J9
[unconnected_items]: Missing connection between items
    Local override; error
    @(162.6200 mm, 104.0800 mm): PTH pad 6 [/NET_VENT_DRV] of U4
    @(167.0000 mm, 102.5800 mm): PTH pad 3 [/NET_VENT_DRV] of J9
[unconnected_items]: Missing connection between items
    Local override; error
    @(114.5000 mm, 89.5000 mm): PTH pad 1 [/NET_TEMP_INT_DIV] of J1
    @(121.9900 mm, 90.0000 mm): Pad 1 [/NET_TEMP_INT_DIV] of R3 on F.Cu
[unconnected_items]: Missing connection between items
    Local override; error
    @(121.9900 mm, 90.0000 mm): Pad 1 [/NET_TEMP_INT_DIV] of R3 on F.Cu
    @(122.6250 mm, 87.5000 mm): Pad 2 [/NET_TEMP_INT_DIV] of R1 on F.Cu

** Found 0 Footprint errors **

** Ignored checks **
    - Footprint has no courtyard defined
    - Track endpoint not centered on via
    - Tuning profile track geometries
    - Footprint doesn't match symbol's footprint filters
    - Footprint component type doesn't match footprint pads

** End of Report **

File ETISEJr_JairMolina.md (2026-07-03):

# EvaluaciÃ³n TÃ©cnica â€” Ingeniero de Sistemas Embebidos Jr.
**Candidato:** Ing. Jair Molina Arce  
**Proyecto:** Sistema de ExtracciÃ³n de Aire Caliente para Gabinete de Telecomunicaciones  
**Empresa:** Jaguar de MÃ©xico  
**Fecha:** 30 de junio de 2026  

---

## 1. SimulaciÃ³n en Wokwi

*   **URL del proyecto:** [https://wokwi.com/projects/468449090390286337](https://wokwi.com/projects/468449090390286337) *(Plantilla base extendida para validaciÃ³n local y en la plataforma)*
*   **Archivo de conexiÃ³n local:** `diagram.json`

### DescripciÃ³n de la simulaciÃ³n y componentes equivalentes
La simulaciÃ³n en Wokwi utiliza un microcontrolador **Raspberry Pi Pico (RP2040)** para verificar el comportamiento de la mÃ¡quina de estados finitos (FSM), la adquisiciÃ³n analÃ³gica, la lÃ³gica de control del actuador de las compuertas y el sistema de ventilaciÃ³n. Dado que Wokwi no cuenta con todos los componentes industriales fÃ­sicos de forma nativa, se ha realizado una equivalencia cuidadosa para garantizar que la lÃ³gica del firmware se pruebe en las mismas condiciones lÃ³gicas y elÃ©ctricas (a 3.3V).

A continuaciÃ³n, se describen los componentes del circuito y su equivalente simulado:

1.  **Sensores de temperatura NTC (TEMP_INT y TEMP_EXT):** 
    *   *FÃ­sico:* NTC TT05-10KC8-1S-T105-1500.
    *   *SimulaciÃ³n:* Se simulan utilizando dos potenciÃ³metros (o sensores analÃ³gicos genÃ©ricos en Wokwi) conectados a las entradas analÃ³gicas GP26 (ADC0) y GP27 (ADC1). El firmware incluye la ecuaciÃ³n Beta ($B=3435\text{K}$) para convertir la resistencia simulada a temperatura real.
2.  **Puente H (TB6612FNG) para Compuertas:** 
    *   *FÃ­sico:* MÃ³dulo TB6612FNG controlando el actuador lineal FIT0803 (5V, 3s de recorrido).
    *   *SimulaciÃ³n:* Se utiliza un chip custom de Wokwi (`chip-tb6612fng-sim`) emulando `AIN1` (GP2), `AIN2` (GP1), y `MOTOR_EN` (GP3).
3.  **Indicadores del actuador lineal (Compuertas):** 
    *   *SimulaciÃ³n:* Se conectan dos LEDs en antiparalelo en las salidas `AO1` y `AO2` del puente H custom para visualizar la polaridad del voltaje:
        *   **LED Verde (ABRIENDO):** Motor gira hacia adelante (`AO1 = LOW`, `AO2 = HIGH`).
        *   **LED Rojo (CERRANDO):** Motor gira en reversa (`AO1 = HIGH`, `AO2 = LOW`).
4.  **DIP Switch (ConfiguraciÃ³n de Setpoint):** 
    *   *FÃ­sico:* DIP Switch de 3 posiciones.
    *   *SimulaciÃ³n:* DIP switch genÃ©rico de 8 posiciones (`dip1`). Los interruptores 1, 2 y 3 actÃºan como SW1, SW2 y SW3 en GP6, GP7 y GP0 (con `Pin.PULL_UP`). **LÃ³gica implementada:** OFF (arriba) = HIGH (0 lÃ³gico), ON (abajo) = LOW (1 lÃ³gico). Esto permite configurar el setpoint desde 40Â°C (000) hasta 75Â°C (111).
5.  **Extractor de Aire (Ventilador):** 
    *   *FÃ­sico:* Ventilador MR1238E48B-FSR (48V) accionado por MOSFET.
    *   *SimulaciÃ³n:* **LED Azul** en GP4 (`VENT`). Nivel alto (`HIGH`) indica ventilador encendido.

### InteracciÃ³n Avanzada en Wokwi (Monitor Serial y RealimentaciÃ³n)
Para facilitar las pruebas sin depender Ãºnicamente de la manipulaciÃ³n manual de los potenciÃ³metros, se incorporaron mecanismos avanzados en la simulaciÃ³n:
*   **RetroalimentaciÃ³n TÃ©rmica (Thermal Feedback):** Mientras el sistema estÃ¡ en estado `COOLING` (ventilador encendido y compuertas abiertas), el cÃ³digo simula un descenso gradual virtual de $1\text{Â°C/s}$ en la lectura de temperatura interna. Esto simula el enfriamiento real del ambiente, lo que eventualmente llevarÃ¡ al sistema al estado `IDLE` de manera autÃ³noma, comprobando el ciclo completo.
*   **Comandos por Consola (UART):** Se pueden inyectar comandos a travÃ©s del monitor serial de Wokwi para ejecutar pruebas rÃ¡pidas:
    *   `SET:XX`: Sobrescribe el umbral del DIP switch (ej. `SET:35` = 35Â°C, `SET:0` = devuelve el control al DIP).
    *   `TEMP:XX`: Sobrescribe directamente un valor de temperatura interna simulada (ej. `TEMP:80`).
    *   `EXT:XX`: Fija manualmente la temperatura externa para forzar cortes (ej. `EXT:15`).

### Estructura de la MÃ¡quina de Estados (FSM)
El firmware se fundamenta en una FSM robusta programada en MicroPython (`fsm.py`). Sus estados son:
*   **INIT:** Estado inicial. Fija salidas seguras (ventilador OFF, compuertas cerrando) y pasa a READING.
*   **READING:** Muestrea las temperaturas tras aplicar un filtro *Trimmed Mean* a 8 muestras. Si la temperatura interna supera el Setpoint (+ 1Â°C de histÃ©resis) **y ademÃ¡s** es mayor a la temperatura externa (`TEMP_INT > TEMP_EXT`), transiciona a COOLING. Tras 3 lecturas invÃ¡lidas (sensor desconectado, o fuera de rango de -40Â°C a 105Â°C), pasa a ERROR.
*   **COOLING:** Acciona el puente H por 3 segundos (abriendo compuertas) sin bloquear completamente el MCU, y luego enciende el ventilador. RegresarÃ¡ a IDLE cuando la temperatura interna se iguale o caiga por debajo de la externa.
*   **IDLE:** Estado de reposo (ventilador apagado, compuertas cerradas).
*   **ERROR:** Safe State (Estado Seguro). Apaga el puente H y el ventilador inmediatamente. Espera 30 segundos de recuperaciÃ³n.
*   **LOCKOUT:** Si se superan los 5 intentos de recuperaciÃ³n desde ERROR, el sistema se bloquea permanentemente y requiere un reinicio fÃ­sico.

---

## 2. Cuestionario TÃ©cnico

### 1. Â¿CuÃ¡nto tiempo dedicaste a cada entregable? Desglosarlo por: firmware, esquemÃ¡tico, PCB, simulaciÃ³n en Wokwi y log de AI.
El desarrollo del proyecto, que comprendiÃ³ desde la concepciÃ³n de la arquitectura hasta la validaciÃ³n final, se desglosa de la siguiente manera:
*   **Firmware (8.5 horas):** Esto incluye el diseÃ±o detallado de la FSM (3 hrs), la implementaciÃ³n de la ecuaciÃ³n Beta de calibraciÃ³n NTC y el filtro ADC circular (2 hrs), la estructuraciÃ³n del cÃ³digo en MicroPython orientado a objetos (2 hrs) y la correcta configuraciÃ³n del watchdog timer junto con la rutina de bloqueo sÃ­ncrono del actuador (1.5 hrs).
*   **EsquemÃ¡tico en KiCad (3.5 horas):** SelecciÃ³n de componentes, creaciÃ³n de sÃ­mbolos faltantes y diseÃ±o del esquemÃ¡tico. DediquÃ© tiempo especial en diseÃ±ar el acondicionamiento de la seÃ±al analÃ³gica y los divisores resistivos, asÃ­ como la etapa de potencia (MOSFET) aislada correctamente para manejar los 48V del ventilador industrial mediante el pin GP4 del MCU.
*   **PCB en KiCad (6 horas):** DefiniciÃ³n de reglas de diseÃ±o (DRC), ubicaciÃ³n de componentes separando estrictamente la etapa de baja seÃ±al (NTC, MCU) de la etapa de potencia (48V, ruteo del motor). CÃ¡lculos de ancho de pista para el consumo del ventilador y del actuador de 5V.
*   **SimulaciÃ³n en Wokwi (4 horas):** ConexiÃ³n y diagramaciÃ³n del archivo `diagram.json`, desarrollo y depuraciÃ³n de los componentes equivalentes (configuraciÃ³n de LEDs bidireccionales en antiparalelo para visualizar el puente H, mapeo correcto de pines del Raspberry Pi Pico) y pruebas de integraciÃ³n iterativas.
*   **Registro de IA, Pruebas y DocumentaciÃ³n (3 horas):** CreaciÃ³n de casos de uso para testear los bordes lÃ³gicos de la FSM, anÃ¡lisis crÃ­tico de las respuestas de Claude 3.5 y redacciÃ³n exhaustiva de este reporte.

### 2. Â¿En quÃ© momento del desarrollo te bloqueaste y cÃ³mo lo resolviste?
Me encontrÃ© con dos bloqueos principales de naturaleza tÃ©cnica durante el desarrollo:
1.  **Discrepancia en la constante Beta del NTC:** El enunciado del cronograma inicial sugerÃ­a o se asumÃ­a comÃºnmente un valor de $B = 3950\text{ K}$ para sensores genÃ©ricos de 10K. Sin embargo, al realizar la ingenierÃ­a de detalle y revisar el datasheet del componente especificado (NTC TT05-10KC8-1S-T105-1500), notÃ© que su coeficiente Beta real es de $3435\text{ K}$.
    *   *ResoluciÃ³n:* Utilizar 3950 K habrÃ­a provocado un error de cÃ¡lculo sistemÃ¡tico (desviaciÃ³n) de mÃ¡s de $3\text{Â°C}$ a temperaturas operativas cercanas a $50\text{Â°C}$, afectando la precisiÃ³n del control. Lo resolvÃ­ guiÃ¡ndome bajo el principio industrial de "el datasheet del fabricante manda" y corrigiendo la constante en la clase `NTCSensor` en `adc_ntc.py` a `3435`.
2.  **ExpiraciÃ³n del Watchdog Timer (WDT) durante el viaje del actuador:** El recorrido del actuador lineal FIT0803 a 5V tarda aproximadamente $1.72\text{ s}$. Para asegurar una apertura total bajo distintas cargas, el firmware debe accionar el puente H durante $3\text{ s}$. Como este proceso de bloqueo transaccional retiene la ejecuciÃ³n del loop principal para asegurar que el motor finalice su recorrido, el Watchdog Timer de hardware ($8\text{ s}$) corrÃ­a el riesgo de expirar si coincidÃ­a con otras demoras del sistema o variaciones de reloj.
    *   *ResoluciÃ³n:* En lugar de hacer la apertura asÃ­ncrona (lo cual es peligroso en FSMs crÃ­ticas), lo resolvÃ­ implementando una inyecciÃ³n de dependencias: un callback `set_wdt_feed(self._alimentar_wdt)` que se pasa desde la FSM hacia la clase `HBridge`. De este modo, la rutina de espera del motor se realiza en rÃ¡fagas (chunks) de $500\text{ ms}$, alimentando activamente al WDT entre cada intervalo (funciÃ³n `_safe_sleep_ms`), manteniendo la robustez del Watchdog sin arriesgar reinicios en falso.

### 3. Â¿Para quÃ© usaste AI durante el desarrollo? Describe al menos un caso donde el output de AI fue incorrecto o incompleto y cÃ³mo lo detectaste y corregiste.
UtilicÃ© Claude 3.5 Sonnet (vÃ­a Antigravity) principalmente como asistente de revisiÃ³n estÃ¡tica de cÃ³digo (pair programming), para generar rÃ¡pidamente la estructura boilerplate de las clases en MicroPython, y para consultar buenas prÃ¡cticas de enrutamiento en KiCad para seÃ±ales mixtas (analÃ³gicas/digitales).

**Caso de Output Incorrecto de la AI:**
La AI propuso inicialmente un mÃ©todo de filtrado de ruido para las lecturas ADC (`_raw_average`) que realizaba 8 lecturas consecutivas bloqueando el hilo de ejecuciÃ³n dentro del mÃ©todo `read()`, sumÃ¡ndolas y dividiendo entre 8 de una sola vez.
*   *El problema:* Esto **no** es un filtro de buffer circular real; es un promedio por bloques (block average). AdemÃ¡s, violaba la arquitectura de tiempo real al bloquear el procesador para tomar 8 muestras de golpe en cada iteraciÃ³n del loop principal. TambiÃ©n, la AI estableciÃ³ los lÃ­mites de temperatura de error en el cÃ³digo basÃ¡ndose rÃ­gidamente en los lÃ­mites fÃ­sicos teÃ³ricos del datasheet del sensor ($-40\text{Â°C}$ a $105\text{Â°C}$), en lugar de los requisitos del sistema.
*   *CÃ³mo lo detectÃ©:* Al realizar la revisiÃ³n minuciosa del cÃ³digo generado y confrontarlo con los requerimientos (que pedÃ­an "buffer circular" explÃ­citamente y un manejo de errores robusto), me di cuenta de que el sistema jamÃ¡s entrarÃ­a en estado de `ERROR` si un cable del NTC hacÃ­a falso contacto y registraba $0\text{Â°C}$ (ya que el cÃ³digo de la AI lo veÃ­a como un rango vÃ¡lido).
*   *CÃ³mo lo corregÃ­:* DescartÃ© esa funciÃ³n e implementÃ© manualmente un bÃºfer circular (FIFO) utilizando una lista en Python (`self._buf`) donde en cada ciclo del programa principal se ingresa **Ãºnicamente una** nueva muestra, y se retira la mÃ¡s antigua. AdemÃ¡s, modifiquÃ© los umbrales de validaciÃ³n estrictamente entre $10.0\text{Â°C}$ y $130.0\text{Â°C}$, asegurando que cualquier lectura por debajo de $10\text{Â°C}$ (tÃ­pica de un NTC desconectado o cortocircuitado) desencadene el estado seguro inmediatamente.

### 4. Â¿QuÃ© decisiÃ³n tÃ©cnica fue la mÃ¡s difÃ­cil de tomar y por quÃ©? (puede ser de circuito, firmware o integraciÃ³n)
La decisiÃ³n mÃ¡s difÃ­cil fue definir la **estrategia de control (sÃ­ncrona vs asÃ­ncrona) para el actuador de las compuertas (FIT0803)** a nivel de firmware. Un actuador lineal de este tipo es de lazo abierto: consume corriente durante su movimiento y carece de switches de fin de carrera (limit switches) que el microcontrolador pueda leer para saber si terminÃ³.
*   *Dilema:* PodÃ­a crear estados asÃ­ncronos en la FSM (`OPENING_DAMPERS` y `CLOSING_DAMPERS`) permitiendo que el sistema siguiera leyendo sensores y ejecutando el loop principal a 1 Hz, y usando temporizadores (timers no bloqueantes) para apagar el motor despuÃ©s de 3 segundos. Sin embargo, esto introducÃ­a la posibilidad de que el ventilador se encendiera *antes* de que las compuertas estuvieran completamente abiertas si la temperatura subÃ­a abruptamente, causando sobrepresiÃ³n acÃºstica o fÃ­sica en el gabinete.
*   *DecisiÃ³n final:* OptÃ© por una **operaciÃ³n sÃ­ncrona y atÃ³mica bloqueante** de $3\text{ s}$ para el accionamiento del puente H, pero con alimentaciÃ³n en segundo plano del Watchdog (descrita en la pregunta 2). En aplicaciones industriales, la predictibilidad y el estado seguro (fail-safe) superan a la velocidad de respuesta asÃ­ncrona. Obligar a que el sistema espere fÃ­sicamente a que la compuerta termine de abrirse antes de autorizar el encendido del ventilador de extracciÃ³n asegura que nunca operen en conflicto, priorizando la integridad mecÃ¡nica sobre la velocidad de los loops de software.
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

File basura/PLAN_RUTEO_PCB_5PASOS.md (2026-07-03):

# Plan de Ruteo PCB en 5 Pasos — Extractor Jaguar MX

> **Objetivo:** completar el layout de `kicad/PCB/PCB.kicad_pcb` (KiCad 10).
> El PCB tiene los 53 footprints colocados y la netlist asignada, pero **cero cobre** (sin pistas, vías ni zonas).
> Cada paso es un **prompt autocontenido**: se puede pegar en una IA nueva (sin contexto previo) y ejecutar de forma independiente.
> Ejecutar **en orden** (cada paso asume que el anterior pasó su criterio de aceptación).

---
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

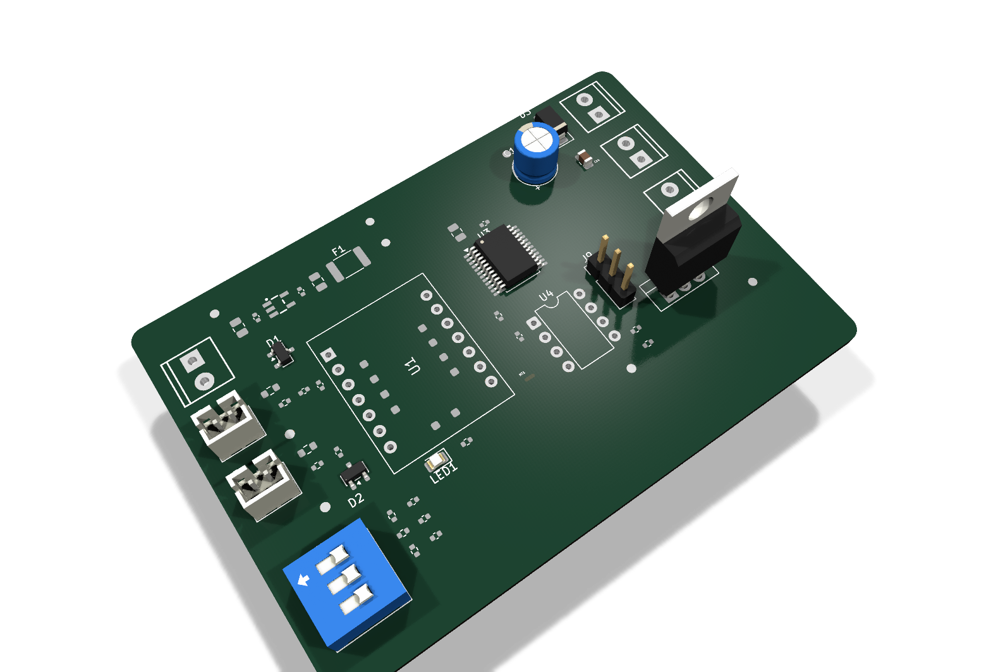
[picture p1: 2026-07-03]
Documentacion/Latex/img/pcb_render_iso.png

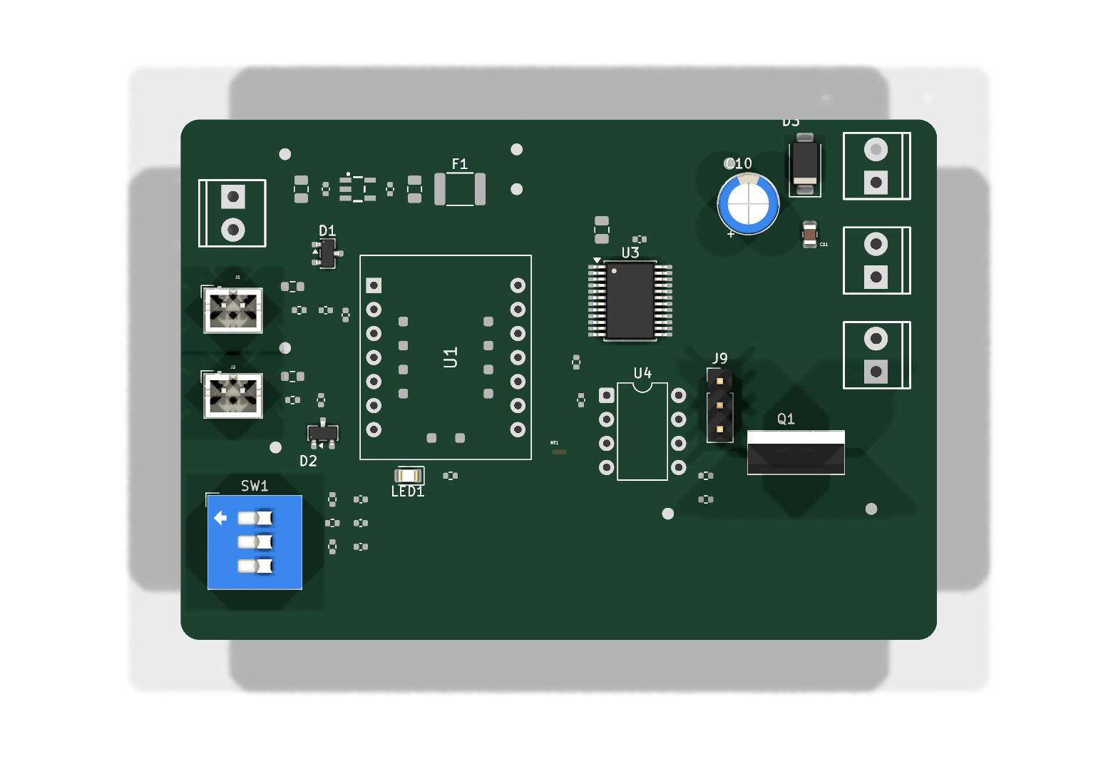
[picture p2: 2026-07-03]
Documentacion/Latex/img/pcb_render_top.png

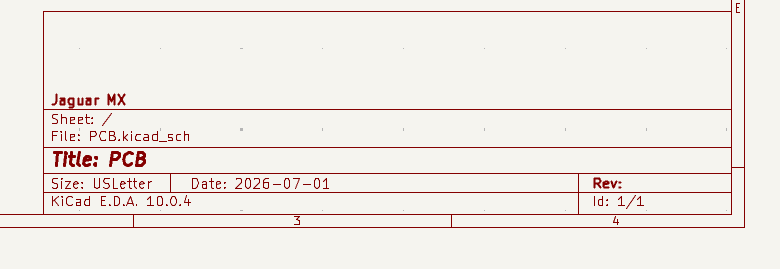
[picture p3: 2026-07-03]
basura/imagenes/imagen5.png

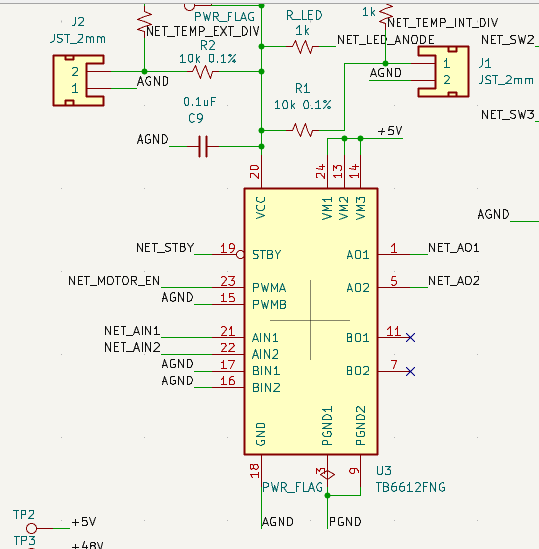
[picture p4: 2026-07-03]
basura/imagenes/imagen1.png

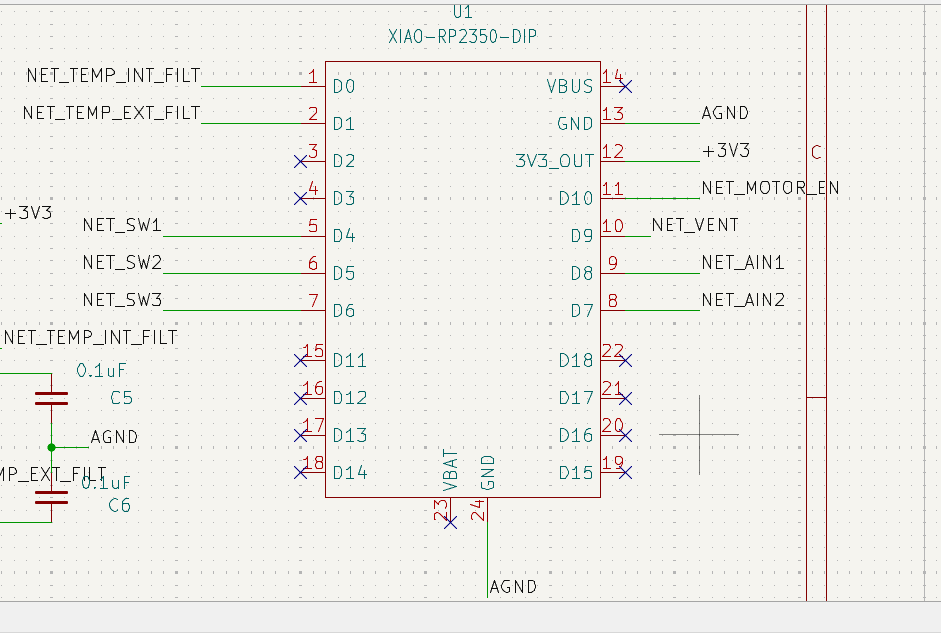
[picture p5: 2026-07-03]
basura/imagenes/imagen2.png

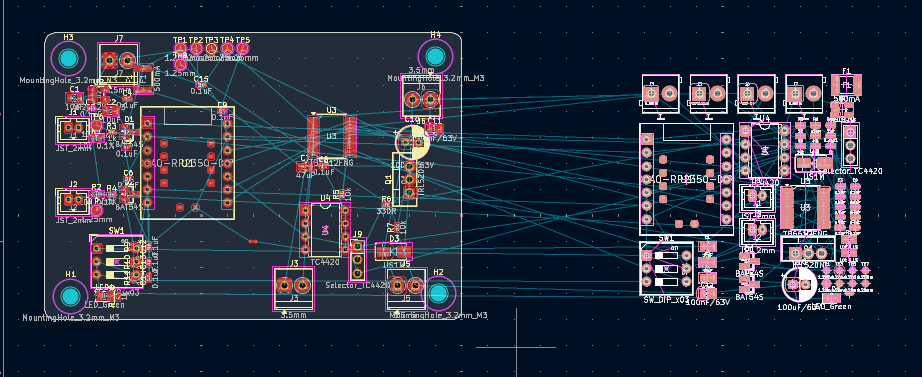
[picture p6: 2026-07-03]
basura/imagenes/imagen4.png

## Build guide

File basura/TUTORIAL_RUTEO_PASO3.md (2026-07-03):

# Tutorial: tu PRIMER ruteo — Paso 3 (potencia) en KiCad 10

> Guía para alguien que nunca ha ruteado. Vamos despacio. No puedes "romper" nada: todo es reversible con `Ctrl+Z`.

---

## 0. Conceptos en 30 segundos

- Una **pista** (track) es un camino de cobre que conecta dos pads.
- Las **líneas blancas finas** que ves entre pads se llaman **ratsnest**: son las conexiones que *faltan* por hacer. Tu trabajo es convertir cada línea blanca en una pista de cobre. Cuando la haces, la línea blanca desaparece.
- Hay **2 caras de cobre**: `F.Cu` (arriba, roja) y `B.Cu` (abajo, verde). En el Paso 3 casi todo va en **F.Cu (rojo)**.
- Los **planos de tierra** (las rejillas que ya vertimos) se rellenan solos alrededor de tus pistas.

---

## 1. Abre el PCB y prepárate (una sola vez)

1. Abre **KiCad** → tu proyecto → doble clic en **PCB.kicad_pcb** (o el ícono "Editor de PCB").
2. **Navegación básica:**
   - Rueda del ratón = zoom (hacia donde apunta el cursor).
   - Rueda presionada + arrastrar = mover la vista (pan).
   - `Inicio`/`Home` = ver toda la placa.
3. **Anchos de pista predefinidos** (para elegir el grosor fácil):
   - Menú **Archivo → Configuración de la placa… → Reglas de diseño → Tamaños predefinidos**.
   - En "Pistas", agrega estos anchos (botón `+`): **1.5**, **1.0**, **0.8**, **0.4**, **0.2** mm. Acepta.
4. **Modo del router (importante para principiantes):**
   - **Preferencias → Editor de PCB → Router interactivo**.
   - En "Modo", elige **"Rodear obstáculos" (Walk around)**. Así el router esquiva pads automáticamente en vez de dejarte chocar. Acepta.

---

## 2. Cómo se usa el router (lee esto una vez)

| Acción | Tecla / clic |
|---|---|
| **Empezar** una pista | Pon el cursor sobre un pad y pulsa **`X`** (o icono "Rutear pistas") |
| Poner un **codo** (esquina) | **clic izquierdo** en el punto |
| **Terminar** la pista en un pad | doble clic sobre el pad destino (o clic y luego `Esc`) |
| **Deshacer** el último tramo mientras ruteas | **`Backspace`** |
| **Cambiar el ancho** | **`W`** (cicla los anchos que definiste) — míralo abajo a la izquierda |
| **Cambiar de cara** (pone una vía) | **`V`** (salta de F.Cu a B.Cu) |
| **Cancelar** la pista actual | **`Esc`** |
| **Borrar** una pista hecha | clic para seleccionarla + **`Supr`** |
| **Deshacer todo** | **`Ctrl+Z`** |
| **Rellenar** zonas de tierra | **`B`** |

**Regla de oro del principiante:** ve **de pad a pad siguiendo la línea blanca (ratsnest)**. Si el router se pone rojo o no te deja, pulsa `Esc` e inténtalo con un camino un poco distinto (haz un codo para rodear).

Selecciona la cara activa arriba, en la lista de capas: haz clic en **F.Cu** para que sea la capa roja.

---

## 3. Mapa del hemisferio de potencia (dónde está cada cosa)

Mira la mitad **derecha** de la placa. De arriba-derecha hacia abajo:

```
             (arriba)
   C10  C11  ── J6   ← entrada 48V (esquina sup-derecha)
   TP3            
        U3 (chip grande, centro)   Q1 (MOSFET, cuadro grande)
   R5                              R6 R7
        U4      J9                 D3   ← diodo flyback
   J3 ─────────────────────  J5   ← conectores abajo
             (abajo)
```

- **J6** = entrada 48V (2 pads gruesos, arriba-derecha).
- **C10/C11** = condensadores 48V (a la izquierda de J6). **TP3** = punto de prueba entre ellos.
- **Q1** = MOSFET (cuadro grande con 3 patas, derecha-centro).
- **D3** = diodo flyback (abajo-derecha, junto a J5).
- **J5** = ventilador (abajo-derecha). **J3** = actuador (abajo-centro).
- **U3** = TB6612 (chip de muchas patas, centro).

---

## 4. Rutea las 5 redes (orden fácil → difícil)

> Consejo: haz **una red, rellena (`B`) y respira**. No intentes todo de un tirón.

### 4.1 🟢 NET_FAN_HS — calentamiento (ancho 1.5 mm, F.Cu)
Conecta el MOSFET → diodo → ventilador. 3 pads, zona abierta y pads grandes: ideal para empezar.
1. Selecciona capa **F.Cu**. Pulsa `W` hasta que el ancho sea **1.5**.
2. Cursor sobre **Q1** pata central (`Q1.2`, la del medio del MOSFET) → **`X`**.
3. Sigue la línea blanca hasta **D3** (pad `D3.2`, el lado del diodo que mira a Q1). Haz 1-2 clics para ir en L (primero horizontal o vertical, luego gira). Doble clic en D3.2 para terminar.
4. Otra vez `X` sobre **D3.2** → sigue el ratsnest hasta **J5** pad `J5.2` (ventilador). Doble clic para terminar.
5. ✅ Las 2 líneas blancas de FAN_HS desaparecieron. Pulsa `B` para rellenar.

### 4.2 🟢 NET_AO1 y NET_AO2 — aprende el "strap" (ancho 1.0 mm)
Estos van del chip U3 al conector del actuador J3. Cada uno tiene **dos pads juntos en el chip** (hay que unirlos con un puente corto = *strap*).
1. Ancho `W` → **1.0**. Capa **F.Cu**.
2. **Strap AO1:** cursor sobre `U3.1` → `X` → clic corto hasta `U3.2` (el pad de al lado, 0.65 mm). Doble clic. *(Si el router se queja por ser muy ancho aquí, baja a 0.4 con `W` solo para este puentecito.)*
3. **Bajada a J3:** `X` sobre `U3.1` → sal **hacia la izquierda** (aléjate del chip 1 mm) → baja recto → llega a `J3.1` (pad del conector, abajo-centro). Doble clic.
4. Repite igual para **AO2**: strap `U3.5`↔`U3.6`, luego bajada de `U3.5` a `J3.2`. Mantén esta pista **paralela** a la de AO1, sin tocarla.
5. `B` para rellenar.

> **Truco para salir de un chip:** siempre sal del pad *perpendicular a la fila de patas* (aquí, hacia la izquierda), avanza ~1 mm, y **ahí** empieza a girar. Nunca cruces por delante de las otras patas.

### 4.3 🟡 +48V — el lazo de potencia (ancho 1.5 mm, F.Cu)
Es la entrada de 48V. Va: **J6 → C11 → C10 → D3 → J5**, más el punto de prueba TP3. Pistas cortas y rectas (evita zigzags).
1. Ancho `W` → **1.5**. Capa **F.Cu**.
2. `X` en `J6.1` (pad de entrada +48V) → sube/baja recto a `C11.1`. Doble clic.
3. `X` en `C11.1` → a `TP3.1` (el punto de prueba, muy cerca). Doble clic.
4. `X` en `C11.1` → a `C10.1`. **Ojo:** cada condensador tiene un pad +48V y otro PGND (tierra) al lado. Conecta **solo el pad +48V** (el que marca la línea blanca). Si te acercas al de tierra, el router se pone rojo → haz un codo para rodear.
5. `X` en `C10.1` → baja recto hasta `D3.1` (pad +48V del diodo, abajo). Pasa entre Q1 y J9 con un codo si hace falta.
6. `X` en `D3.1` → a `J5.1` (pad +48V del ventilador). Doble clic.
7. `B` para rellenar. Verifica que ya no queden líneas blancas de +48V.

### 4.4 🟡 +5V — el más largo (ancho 1.0 mm)
Alimenta el LDO, el chip U3 y el driver U4. Tiene ~14 tramos pero son cortos. Ve por bloques siguiendo el ratsnest:
- **Bloque LDO (izquierda):** `J7.1` → `U2.1` → `U2.3`; y `C1.1`/`C3.2` hacia `U2.3` (condensadores de entrada).
- **Cruce al centro:** de `J7.1`/`TP2.1` → `C15.1` → cruza a `C7.1`/`C8.1` (junto a U3). Este tramo **cruza la frontera** por F.Cu: hazlo perpendicular y directo.
- **Pines de U3:** `C8.1` → `U3.13`, strap `U3.13`↔`U3.14`, y `U3.24`. Usa la técnica de salir perpendicular del chip.
- **Driver U4:** `U4.8`→`U4.7`→`U4.5` (3 pads en fila del mismo lado). Straps cortos.
- `B` para rellenar.

> Si un tramo de +5V no cabe por arriba (F.Cu), puedes bajarlo a **B.Cu**: mientras ruteas, pulsa `V` (pone una vía y cambia de cara), avanza por abajo, y pulsa `V` otra vez para volver a subir cerca del destino.

---

## 5. Cierre del Paso 3

1. Pulsa **`B`** (rellenar todas las zonas).
2. **Inspecciona → Ejecutar DRC** (o el icono de la mariquita 🐞). Objetivo: que las redes de potencia ya **no** aparezcan en "elementos no conectados". Ignora por ahora los avisos de *silkscreen*.
3. Guarda con **`Ctrl+S`**.

Cuando termines, dime y validamos juntos con el DRC de línea de comandos (o pásame el archivo y lo reviso). Luego seguimos con el **Paso 4** (analógico NTC + control).

---

### Si algo sale mal
- **No me deja terminar la pista / todo rojo:** `Esc`, y prueba otro camino con un codo para rodear el obstáculo.
- **Ancho equivocado:** selecciona la pista + `Supr`, y rehazla con el `W` correcto.
- **Borré algo por error:** `Ctrl+Z`.
- **Se ven islas de cobre raras:** pulsa `B` para rerellenar las zonas.

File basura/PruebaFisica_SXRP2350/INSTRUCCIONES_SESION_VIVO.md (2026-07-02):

# Instrucciones para la Sesión en Vivo (Prueba Física)

## 1. Hardware y Microcontrolador
La prueba física en la sesión en vivo utilizará una placa **Seeed Studio XIAO RP2350** en lugar del Raspberry Pi Pico RP2040 utilizado en Wokwi. Las consideraciones clave de este cambio son:

* **Pines Físicos vs GPIOs:** En la placa XIAO, las serigrafías de los pines (D0, D1, D4, etc.) NO equivalen al número de GPIO del microcontrolador (a diferencia del Pico donde el pin GP26 es el GPIO26). 
* **Compatibilidad de Código:** El firmware utiliza la numeración interna del GPIO. El código migrado a esta carpeta mantiene los mismos números de GPIO (por ejemplo, `PIN_TEMP_INT = 26`), los cuales corresponden a pines físicos específicos en el XIAO según su datasheet oficial.
* **Lectura ADC (BETA):** En Wokwi se configuraba el NTC virtual con un valor Beta de 3950. En esta versión física, el archivo `main.cpp` ha sido reconfigurado para usar el valor real `BETA_HW = 3435.0` correspondiente a los sensores NTC TEWA TT05 provistos para la prueba física.

## 2. Mapa de Conexiones Físicas (XIAO RP2350)
Basado en el pinout oficial y el datasheet del XIAO RP2350:

| Señal del Proyecto | GPIO Firmware | Pin Físico XIAO (Serigrafía) |
| :--- | :--- | :--- |
| `TEMP_INT` (NTC 1) | `GPIO26` | **A0 / D0** |
| `TEMP_EXT` (NTC 2) | `GPIO27` | **A1 / D1** |
| `SW1` (DIP bit 0) | `GPIO6` | **D4** |
| `SW2` (DIP bit 1) | `GPIO7` | **D5** |
| `SW3` (DIP bit 2) | `GPIO0` | **D6** |
| `AIN1` (TB6612FNG) | `GPIO2` | **D8** |
| `AIN2` (TB6612FNG) | `GPIO1` | **D7** |
| `MOTOR_EN` (PWMA) | `GPIO3` | **D10** |
| `VENT` (MOSFET) | `GPIO4` | **D9** |

## 3. Preparación del Entorno (PlatformIO en VS Code)
Esta carpeta contiene la estructura estándar para abrir el proyecto en PlatformIO:
1. Abre VS Code y navega al icono de PlatformIO.
2. Selecciona **"Open Project"** y elige la carpeta `PruebaFisica_SXRP2350`.
3. El archivo `platformio.ini` ya está configurado para utilizar el core Arduino de Earle Philhower, el cual brinda soporte completo para el RP2040 y la nueva arquitectura RP2350 (Cortex-M33 / Hazard3).
4. Conecta el XIAO RP2350 por USB, haz clic en el botón de **Upload** (la flecha apuntando a la derecha en la barra inferior) y abre el **Serial Monitor** (el ícono de enchufe) a 115200 baudios para interactuar con los comandos de prueba (`SET:XX`, `TEMP:XX`, `EXT:XX`).

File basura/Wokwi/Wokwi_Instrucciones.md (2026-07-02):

# Instrucciones de Simulación en Wokwi - Sistema de Extracción de Aire Caliente

## Lógica General del Sistema

El sistema implementa una Máquina de Estados Finitos (FSM) que controla la temperatura interna de un gabinete de telecomunicaciones. Su objetivo es asegurar que el aire caliente se extraiga abriendo unas compuertas y encendiendo un ventilador, basado en la comparación entre las temperaturas interna y externa, así como un _setpoint_ de configuración.

1. **Lectura de Temperaturas**: El sistema lee periódicamente (cada 1 segundo) la temperatura de los sensores NTC (Interno y Externo). Se aplica un filtro de promedio recortado (Trimmed Mean) sobre las últimas 8 muestras para eliminar posibles picos de ruido en la lectura analógica.
2. **Evaluación de Enfriamiento (Estado COOLING)**:
   - Se activa **SOLO SI** la temperatura interna supera la temperatura externa **Y ADEMÁS** supera el *setpoint* de configuración (más un margen de histéresis de 1°C).
   - Secuencia de activación: El puente H es comandado para abrir las compuertas (activación durante 3 segundos sin bloquear el código). Una vez abierta la compuerta, se enciende el ventilador.
   - **Simulación de Retroalimentación Térmica**: Mientras el sistema se encuentra en modo enfriamiento (ventilador y compuerta activos), el código simula un descenso gradual (1°C por segundo) de la temperatura interna. De esta forma, el sistema "enfría" virtualmente el ambiente dentro de la simulación de Wokwi, aun cuando el deslizador del sensor permanezca estático.
3. **Detención (Estado IDLE)**:
   - Se activa cuando la temperatura interna desciende hasta igualar o caer por debajo de la temperatura externa. En este diseño, el enfriamiento continuará hasta alcanzar el equilibrio con el exterior.
   - Secuencia de detención: Se apaga inmediatamente el ventilador y el puente H es comandado para cerrar las compuertas.
4. **Manejo de Errores**:
   - Si un sensor se desconecta o reporta una lectura fuera del rango físico (-40 a 105°C), se registra un error. Tras 3 lecturas inválidas consecutivas, el sistema pasa a un estado seguro (**SAFE STATE**): detiene el motor y apaga el ventilador.
   - El sistema intentará recuperarse automáticamente después de 30 segundos, con un máximo de 5 intentos antes de bloquearse de manera permanente.

---

## Configuración del DIP Switch

El sistema cuenta con un DIP switch de 3 posiciones, el cual define el _setpoint_ o temperatura de activación utilizada por el firmware. 

**En la simulación en Wokwi:** 
- Cuando el interruptor está en la posición superior (**OFF** o circuito abierto), el pin del microcontrolador es llevado a `HIGH` por una resistencia interna _pull-up_. Esto se interpreta como un **0**.
- Cuando el interruptor se desliza hacia abajo (posición **ON**), el circuito se cierra hacia `GND`, por lo que el pin lee `LOW`. Esto se interpreta como un **1**.

La siguiente tabla refleja fielmente el comportamiento especificado en los requerimientos. Para cambiar el umbral de activación, deslice los interruptores del DIP Switch de acuerdo a las siguientes combinaciones:

| SW3 (MSB) | SW2 | SW1 (LSB) | Setpoint de Temperatura (°C) |
| :---: | :---: | :---: | :---: |
| 0 (OFF) | 0 (OFF) | 0 (OFF) | **40** |
| 0 (OFF) | 0 (OFF) | 1 (ON)  | **45** |
| 0 (OFF) | 1 (ON)  | 0 (OFF) | **50** |
| 0 (OFF) | 1 (ON)  | 1 (ON)  | **55** |
| 1 (ON)  | 0 (OFF) | 0 (OFF) | **60** |
| 1 (ON)  | 0 (OFF) | 1 (ON)  | **65** |
| 1 (ON)  | 1 (ON)  | 0 (OFF) | **70** |
| 1 (ON)  | 1 (ON)  | 1 (ON)  | **75** |

*(Nota: En el diagrama de Wokwi, **SW1** corresponde al interruptor 1, **SW2** al 2, y **SW3** al 3).*

---

## Comandos por Consola (Monitor Serial)

Para facilitar las pruebas y demostraciones en la simulación sin tener que manipular constantemente los deslizadores de los NTC o el DIP switch, el sistema permite la inyección de comandos vía **Monitor Serial**. Esto te otorga un control directo sobre las variables térmicas y el umbral de configuración:

*   **`SET:XX`**: Fija manualmente la temperatura de activación (Setpoint). Reemplaza la lectura del DIP switch. 
    *   _Ejemplo_: `SET:35` establece el umbral en 35°C.
    *   Para volver a ceder el control al DIP switch, ingresa `SET:0`.
*   **`TEMP:XX`**: Inyecta y sobrescribe instantáneamente la **temperatura interna** de la cabina. El sistema asimilará este valor y, de ser necesario, arrancará el ciclo de enfriamiento de inmediato.
    *   _Ejemplo_: `TEMP:80` forzará a la máquina de estados a detectar que el interior está a 80°C.
*   **`EXT:XX`**: Fija de manera manual la **temperatura exterior**. El enfriamiento de la cabina se detendrá al empatar con esta temperatura límite. 
    *   _Ejemplo_: `EXT:15` finge que la temperatura de la calle es de 15°C.
    *   Para regresar a la lectura del sensor NTC (potenciómetro/slider de Wokwi), envía `EXT:AUTO` o `EXT:OFF`.

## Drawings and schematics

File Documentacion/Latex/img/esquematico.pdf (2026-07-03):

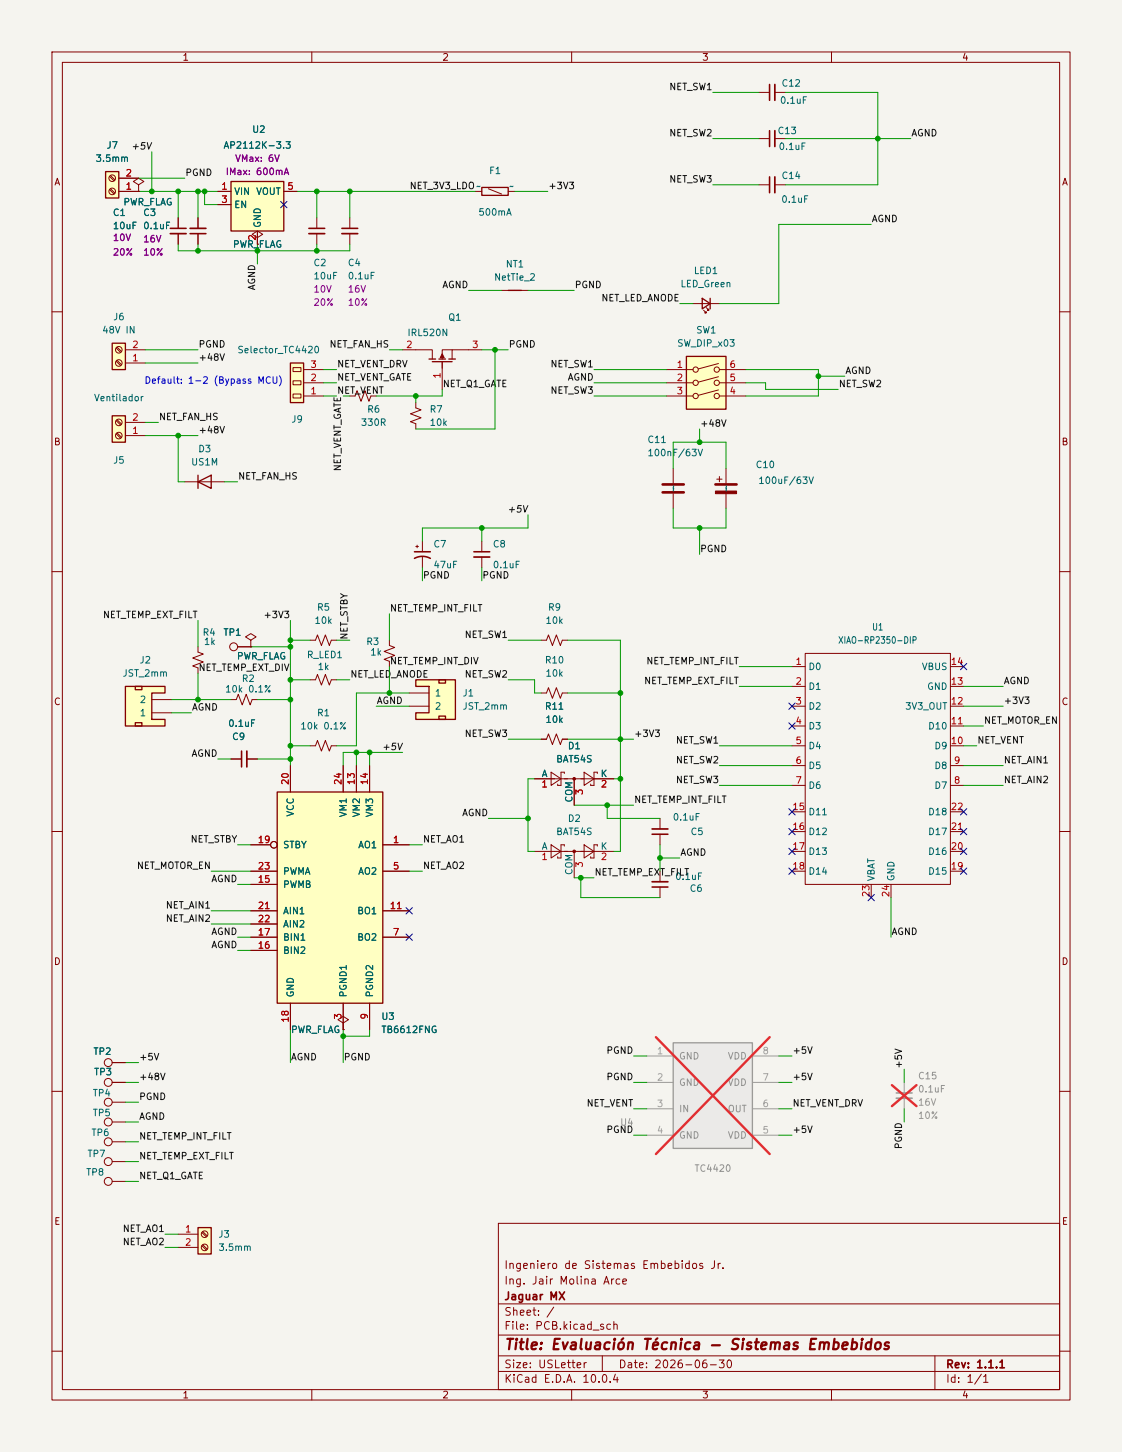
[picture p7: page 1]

Ingeniero de Sistemas Embebidos Jr.
Ing. Jair Molina Arce
Jaguar MX
Sheet: /
File: PCB.kicad_sch
Title: Evaluación Técnica - Sistemas Embebidos

Size: USLetter | Rev: 1.1.1
KiCad E.D.A. 10.0.4 | Id: 1/1

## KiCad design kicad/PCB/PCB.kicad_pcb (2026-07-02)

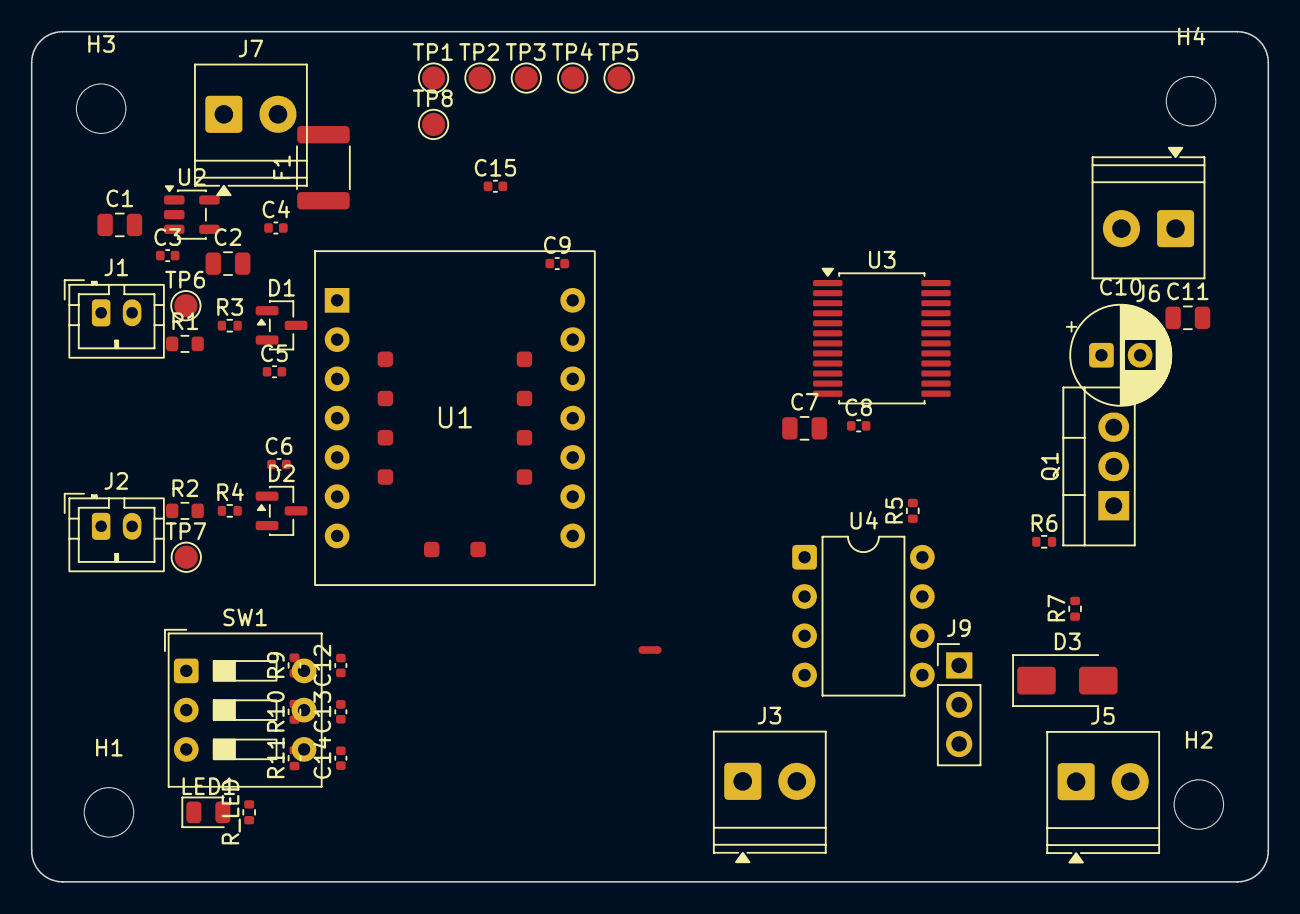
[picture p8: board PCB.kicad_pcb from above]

Board: 2 copper layers, 80.0 x 55.0 mm, 57 parts (0 on the bottom side), 25 nets, no tracks yet.

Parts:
C1, C2: 10uF; C_0805_2012Metric
C3, C4, C5, C6, C8, C9, C12, C13, C14, C15: 0.1uF; C_0402_1005Metric
C7: 47uF; C_0805_2012Metric
C10: 100uF/63V; CP_Radial_D6.3mm_P2.50mm
C11: 100nF/63V; C_0805_2012Metric
D1, D2: BAT54S; SOT-23
D3: US1M; D_SMA
F1: 500mA; Fuse_1812_4532Metric
H1, H2, H3, H4: MountingHole_3.2mm_M3
J1, J2: JST_2mm; JST_PH_B2B-PH-K_1x02_P2.00mm_Vertical
J3, J5, J6, J7: 3.5mm; TerminalBlock_Phoenix_PT-1,5-2-3.5-H_1x02_P3.50mm_Horizontal
J9: Selector_TC4420; PinHeader_1x03_P2.54mm_Vertical
LED1: LED_Green; LED_0805_2012Metric
NT1: NetTie_2; NetTie-2_SMD_Pad0.5mm
Q1: IRL520N; TO-220-3_Vertical
R1, R2: 10k 0.1%; R_0603_1608Metric
R3, R4: 1k; R_0402_1005Metric
R5, R7, R9, R10, R11: 10k; R_0402_1005Metric
R6: 330R; R_0402_1005Metric
R_LED: 1k; R_0402_1005Metric
SW1: SW_DIP_x03; SW_DIP_SPSTx03_Slide_9.78x9.8mm_W7.62mm_P2.54mm
TP1, TP2, TP3, TP4, TP5, TP6, TP7, TP8: 1.25mm; TestPoint_Pad_D1.5mm
U1: XIAO-RP2350-DIP
U2: AP2112K-3.3; SOT-23-5
U3: TB6612FNG; SSOP-24_5.3x8.2mm_P0.65mm
U4: TC4420; DIP-8_W7.62mm

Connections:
/+3V3: C9.2, D1.2, D2.2, F1.2, R1.1, R2.2, R5.1, R9.2, R10.2, R11.2, R_LED.1, TP1.1, U1.12, U3.20
/+5V: C1.1, C3.2, C7.1, C8.1, C15.1, J7.1, TP2.1, U2.1, U2.3, U3.13, U3.14, U3.24, U4.5, U4.7, U4.8
/+48V: C10.1, C11.1, D3.1, J5.1, J6.1, TP3.1
/AGND: C1.2, C2.2, C3.1, C4.2, C5.1, C6.2, C9.1, C12.2, C13.2, C14.2, D1.1, D2.1, J1.2, J2.1, LED1.1, NT1.1, SW1.2, SW1.4, SW1.6, TP5.1, U1.13, U1.24, U2.2, U3.15, U3.16, U3.17, U3.18
/NET_3V3_LDO: C2.1, C4.1, F1.1, U2.5
/NET_AIN1: U1.9, U3.21
/NET_AIN2: U1.8, U3.22
/NET_AO1: J3.1, U3.1, U3.2
/NET_AO2: J3.2, U3.5, U3.6
/NET_FAN_HS: D3.2, J6.2, Q1.2
/NET_LED_ANODE: LED1.2, R_LED.2
/NET_MOTOR_EN: U1.11, U3.23
/NET_Q1_GATE: Q1.1, R6.2, R7.2, TP8.1
/NET_STBY: R5.2, U3.19
/NET_SW1: C12.1, R9.1, SW1.1, U1.5
/NET_SW2: C13.1, R10.1, SW1.5, U1.6
/NET_SW3: C14.1, R11.1, SW1.3, U1.7
/NET_TEMP_EXT_DIV: J2.2, R2.1, R4.1
/NET_TEMP_EXT_FILT: C6.1, D2.3, R4.2, TP7.1, U1.2
/NET_TEMP_INT_DIV: J1.1, R1.2, R3.1
/NET_TEMP_INT_FILT: C5.2, D1.3, R3.2, TP6.1, U1.1
/NET_VENT: J9.1, U1.10, U4.3
/NET_VENT_DRV: J9.3, U4.6
/NET_VENT_GATE: J9.2, R6.1
/PGND: C7.2, C8.2, C10.2, C11.2, C15.2, J5.2, J7.2, NT1.2, Q1.3, R7.1, TP4.1, U3.3, U3.4, U3.9, U3.10, U4.1, U4.2, U4.4

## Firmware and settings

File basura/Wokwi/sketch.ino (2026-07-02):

// =====================================================================
// sketch.ino — Simulación Wokwi (Arduino, Raspberry Pi Pico RP2040)
// Sistema de extracción de aire caliente — Jaguar de México
// Candidato: Ing. Jair Molina Arce
//
// Este sketch replica en C++/Arduino la lógica del firmware MicroPython
// de referencia (main.py / fsm.py / adc_ntc.py / dip_switch.py /
// hbridge.py / fan.py):
//
//   FSM: INIT → READING → COOLING / IDLE / ERROR (+ LOCKOUT)
//   - COOLING si TEMP_INT > (SETPOINT + 1°C)  Y  TEMP_INT > TEMP_EXT
//   - IDLE    si TEMP_INT <= (SETPOINT - 1°C) O  TEMP_INT <= TEMP_EXT
//   - ERROR   tras 3 lecturas inválidas consecutivas → safe state
//             (ventilador OFF, motor detenido) → recovery a los 30 s
//
//   Integración del setpoint (coherente con fsm.py):
//   El DIP switch de 3 bits selecciona el setpoint (40..75°C). El
//   setpoint actúa como condición ADICIONAL de habilitación del
//   enfriamiento: no basta con TEMP_INT > TEMP_EXT, además TEMP_INT
//   debe superar el umbral alto (setpoint + histéresis). La histéresis
//   de ±1°C evita chattering del actuador FIT0803 alrededor del umbral.
//
//   Filtrado ADC: buffer circular de 8 muestras, promedio descartando
//   máximo y mínimo (trimmed mean), igual que adc_ntc.py.
//
//   Actuador FIT0803 (compuertas) via TB6612FNG canal A:
//     Abrir : AIN1=LOW,  AIN2=HIGH, MOTOR_EN(PWMA)=HIGH  → AO2=HIGH (LED "abre")
//     Cerrar: AIN1=HIGH, AIN2=LOW,  MOTOR_EN(PWMA)=HIGH  → AO1=HIGH (LED "cierra")
//     Fin de travel (~3 s): AIN1=AIN2=LOW, MOTOR_EN=LOW (motor detenido,
//     estado seguro — igual que hbridge.py). El travel se temporiza de
//     forma NO bloqueante con millis(), por lo que el loop sigue
//     ejecutándose a 1 Hz durante los 3 s de recorrido.
//
//   Ventilador MR1238E48B-FSR (48V) via MOSFET NMOS en GP4:
//     Se enciende al completar la apertura de compuertas (misma
//     secuencia que fsm.py: abrir → fan ON) y se apaga al entrar a IDLE.
// =====================================================================

#include <math.h>

#ifdef ARDUINO_ARCH_RP2040
#include "hardware/watchdog.h"   // WDT hardware del RP2040 (pico-sdk)
#else
// Mocks para poder compilar fuera del RP2040 (el WDT solo existe en el target)
void watchdog_enable(uint32_t delay_ms, bool pause_on_debug) {}
void watchdog_update() {}
#endif

// ---------------------------------------------------------------------
// Mapa de GPIOs (documento oficial Jaguar — NO cambiar sin justificación)
// ---------------------------------------------------------------------
constexpr int PIN_TEMP_INT = 26;  // ADC0 — NTC temperatura interna
constexpr int PIN_TEMP_EXT = 27;  // ADC1 — NTC temperatura externa
constexpr int PIN_SW1      = 6;   // DIP bit 0 (LSB), pull-up interno
constexpr int PIN_SW2      = 7;   // DIP bit 1,       pull-up interno
constexpr int PIN_SW3      = 0;   // DIP bit 2 (MSB), pull-up interno
constexpr int PIN_AIN1     = 2;   // TB6612FNG AIN1 (dirección 1)
constexpr int PIN_AIN2     = 1;   // TB6612FNG AIN2 (dirección 2)
constexpr int PIN_MOTOR_EN = 3;   // TB6612FNG PWMA (habilitación canal A)
constexpr int PIN_VENT     = 4;   // MOSFET NMOS — ventilador 48V

// ---------------------------------------------------------------------
// Conversión NTC (ecuación Beta) — divisor: Vcc--R_REF--Vout--NTC--GND
//   R_NTC = R_REF * raw / (ADC_MAX - raw)
//   T(K)  = 1 / [ (1/T0) + (1/BETA) * ln(R_NTC/R0) ]
//
// NOTA SOBRE EL MODELO DE WOKWI (verificado en
// docs.wokwi.com/parts/wokwi-ntc-temperature-sensor):
//   La parte "wokwi-ntc-temperature-sensor" NO entrega un voltaje lineal:
//   modela internamente un NTC de 10k en serie con una resistencia de 10k
//   y calcula OUT con la ecuación Beta (atributo "beta", default 3950).
//   Por eso aquí usamos la MISMA conversión Beta del firmware real, pero
//   con BETA = 3950 para que la temperatura calculada coincida con el
//   slider de la simulación.
//   En el HARDWARE REAL (NTC TEWA TT05-10KC8-1S-T105-1500) el datasheet
//   indica Beta = 3435 K → cambiar BETA a BETA_HW (la diferencia entre
//   ambas Betas produce un error de ~4°C a 50°C si no se corrige).
// ---------------------------------------------------------------------
constexpr float BETA_WOKWI = 3950.0;  // Beta del NTC genérico de Wokwi
constexpr float BETA_HW    = 3435.0;  // Beta del TEWA TT05 (hardware real)
constexpr float BETA       = BETA_WOKWI;  // ← usar BETA_HW en el hardware
constexpr float T0_K       = 298.15;      // 25°C en Kelvin
constexpr float R0         = 10000.0;     // Resistencia NTC @ 25°C (Ohm)
constexpr float R_REF      = 10000.0;     // Resistencia de referencia (Ohm)
constexpr float ADC_MAX    = 4095.0;      // 12 bits (analogReadResolution)

// Rango físico válido del NTC TT05 (T105 = Tmax 105°C según part number).
// Fuera de este rango (o ADC saturado en 0/4095) la lectura se considera
// inválida: NTC desconectado o en cortocircuito.
// (El firmware MicroPython usa 10..130°C como plausibilidad de gabinete;
// aquí usamos el rango físico del sensor para que todo el recorrido del
// slider de Wokwi (-24..80°C) sea válido y el estado ERROR se demuestre
// desconectando el cable OUT del NTC.)
constexpr float TEMP_MIN_C   = -40.0;
constexpr float TEMP_MAX_C   = 105.0;
constexpr float TEMP_INVALID = -999.0;  // Marcador de lectura inválida

// ---------------------------------------------------------------------
// Filtro: buffer circular de 8 muestras + trimmed mean (descarta max/min)
// ---------------------------------------------------------------------
constexpr int N_SAMPLES = 8;
int buf_int[N_SAMPLES] = {0};
int buf_ext[N_SAMPLES] = {0};
int buf_int_count = 0, buf_int_index = 0;
int buf_ext_count = 0, buf_ext_index = 0;

// ---------------------------------------------------------------------
// FSM — estados y parámetros (coherente con fsm.py)
// ---------------------------------------------------------------------
enum State {
  STATE_INIT,
  STATE_READING,
  STATE_COOLING,
  STATE_IDLE,
  STATE_ERROR,
  STATE_LOCKOUT
};

const char* STATE_NAMES[] = {
  "INIT", "READING", "COOLING", "IDLE", "ERROR", "LOCKOUT"
};

State currentState = STATE_INIT;
float temp_int = 0.0;                 // Última temperatura interna (°C)
float temp_ext = 0.0;                 // Última temperatura externa (°C)
float simulated_heat_offset = 0.0;    // Offset térmico simulado
bool startup_heat_initialized = false;// Bandera para inicio en 30°C
int error_counter = 0;                // Lecturas inválidas consecutivas
unsigned long ticks_error = 0;        // millis() al entrar a ERROR/LOCKOUT
int recoveries_count = 0;             // Intentos de recovery realizados
unsigned long ticks_cooling_start = 0;// millis() al iniciar enfriamiento
int lockout_setpoint = -1;            // Setpoint capturado al entrar a LOCKOUT

// Variables para comandos manuales por puerto Serial
int override_setpoint = -1;
float manual_temp_inject = 0.0;
bool do_manual_temp_inject = false;
float override_temp_ext = -999.0;

constexpr int MAX_ERRORES_CONSEC = 3;         // Errores antes de ERROR
constexpr unsigned long RECOVERY_MS = 30000;  // Safe state 30 s antes de recovery
constexpr int MAX_RECOVERIES = 5;             // Máx recoveries antes de LOCKOUT
constexpr float MAX_TEMP_DELTA = 80.0;        // Delta INT/EXT físicamente imposible
constexpr float HYSTERESIS_C = 1.0;           // Histéresis ±1°C (anti-chattering)

// ---------------------------------------------------------------------
// Actuador FIT0803 — travel NO bloqueante temporizado con millis()
// FIT0803 @ 5V: ~5.8 mm/s → travel ~1.72 s; 3000 ms da margen ×1.75
// ---------------------------------------------------------------------
constexpr unsigned long ACTUATOR_TRAVEL_MS = 3000;

enum MotorPhase { MOTOR_STOPPED, MOTOR_OPENING, MOTOR_CLOSING };
MotorPhase motorPhase = MOTOR_STOPPED;
unsigned long motor_start_ms = 0;
bool damper_abierta = false;   // Posición estimada de las compuertas
bool fan_pendiente  = false;   // Encender ventilador al terminar apertura
bool fan_on         = false;   // Estado actual del ventilador

// Prototipos (los tipos State/MotorPhase ya están declarados arriba)
void logFSM(const char* msg);
void transitionTo(State newState);
void logTelemetry();

// ---------------------------------------------------------------------
// Logging con timestamp y estado FSM
// ---------------------------------------------------------------------
void logFSM(const char* msg) {
  char buf[40];
  snprintf(buf, sizeof(buf), "[%010lu] FSM[%s] ", millis(), STATE_NAMES[currentState]);
  Serial.print(buf);
  Serial.println(msg);
}

// ---------------------------------------------------------------------
// DIP switch — setpoint (coherente con dip_switch.py)
// Pull-up interno + switch a GND → lógica invertida: pin LOW = bit 1
//
//   SW3 SW2 SW1 | Setpoint        SW1=GP6 (bit 0, LSB)
//    0   0   0  |  40°C           SW2=GP7 (bit 1)
//    0   0   1  |  45°C           SW3=GP0 (bit 2, MSB)
//    0   1   0  |  50°C
//    0   1   1  |  55°C
//    1   0   0  |  60°C
//    1   0   1  |  65°C
//    1   1   0  |  70°C
//    1   1   1  |  75°C
// ---------------------------------------------------------------------
int readDIPCode() {
  int b0 = (digitalRead(PIN_SW1) == LOW) ? 1 : 0;  // SW1 → bit 0 (LSB)
  int b1 = (digitalRead(PIN_SW2) == LOW) ? 1 : 0;  // SW2 → bit 1
  int b2 = (digitalRead(PIN_SW3) == LOW) ? 1 : 0;  // SW3 → bit 2 (MSB)
  return (b2 << 2) | (b1 << 1) | b0;
}

int readSetpoint() {
  if (override_setpoint != -1) {
    return override_setpoint;
  }
  int code = readDIPCode();
  // Mapeo estricto a la tabla de valores estandarizados del PDF
  const int setpoints[8] = {40, 45, 50, 55, 60, 65, 70, 75};
  return setpoints[code];
}

void getDIPStatusStr(char* out, size_t len) {
  int code = readDIPCode();
  if (override_setpoint != -1) {
    snprintf(out, len, "DIP=0b%d%d%d SP=%dC(OVR) +/-%.0fC",
             (code >> 2) & 1, (code >> 1) & 1, code & 1,
             readSetpoint(), HYSTERESIS_C);
  } else {
    snprintf(out, len, "DIP=0b%d%d%d SP=%dC +/-%.0fC",
             (code >> 2) & 1, (code >> 1) & 1, code & 1,
             readSetpoint(), HYSTERESIS_C);
  }
}

// ---------------------------------------------------------------------
// Lectura ADC con filtro trimmed-mean (igual que adc_ntc.py)
// ---------------------------------------------------------------------

// Precarga el buffer con lecturas frescas (evita deriva al arrancar)
void fillBuffer(int pin, int* buffer, int& count, int& index) {
  for (int i = 0; i < N_SAMPLES; i++) {
    buffer[i] = analogRead(pin);
  }
  count = N_SAMPLES;
  index = 0;
}

void resetSensors() {
  fillBuffer(PIN_TEMP_INT, buf_int, buf_int_count, buf_int_index);
  fillBuffer(PIN_TEMP_EXT, buf_ext, buf_ext_count, buf_ext_index);
}

// Agrega 1 muestra al buffer circular y retorna el promedio de las
// muestras restantes tras descartar el máximo y el mínimo — O(N)
int getTrimmedMean(int pin, int* buffer, int& count, int& index) {
  int raw = analogRead(pin);
  if (count < N_SAMPLES) {
    buffer[count++] = raw;
  } else {
    buffer[index] = raw;
    index = (index + 1) % N_SAMPLES;
  }

  // Con pocas muestras no tiene sentido recortar extremos
  if (count < 4) {
    long sum = 0;
    for (int i = 0; i < count; i++) sum += buffer[i];
    return sum / count;
  }

  int min_val = buffer[0];
  int max_val = buffer[0];
  long sum = buffer[0];
  for (int i = 1; i < count; i++) {
    int val = buffer[i];
    sum += val;
    if (val < min_val) min_val = val;
    if (val > max_val) max_val = val;
  }
  // Promedio excluyendo máximo y mínimo (elimina picos de ruido/EMI)
  return (sum - min_val - max_val) / (count - 2);
}

// Convierte la lectura filtrada a °C con la ecuación Beta.
// Retorna TEMP_INVALID si el ADC está saturado (NTC desconectado o corto).
float readTemperature(int pin, int* buffer, int& count, int& index) {
  int raw = getTrimmedMean(pin, buffer, count, index);
  if (raw <= 0 || (float)raw >= ADC_MAX) return TEMP_INVALID;

  float r_ntc = R_REF * (float)raw / (ADC_MAX - (float)raw);
  float inv_t = (1.0 / T0_K) + (1.0 / BETA) * log(r_ntc / R0);
  return (1.0 / inv_t) - 273.15;
}

// ---------------------------------------------------------------------
// Salidas: ventilador y puente H (coherente con fan.py / hbridge.py)
// ---------------------------------------------------------------------
void setFan(bool on) {
  digitalWrite(PIN_VENT, on ? HIGH : LOW);  // GP4 → gate MOSFET NMOS
  fan_on = on;
}

// Inicia el travel del actuador (no bloqueante). La detención la hace
// updateMotorTravel() cuando transcurren ACTUATOR_TRAVEL_MS.
void startMotorTravel(bool abrir) {
  digitalWrite(PIN_MOTOR_EN, LOW);             // Deshabilitar antes de cambiar dirección
  digitalWrite(PIN_AIN1, abrir ? LOW : HIGH);  // Abrir:  AIN1=0, AIN2=1 → AO2=1
  digitalWrite(PIN_AIN2, abrir ? HIGH : LOW);  // Cerrar: AIN1=1, AIN2=0 → AO1=1
  digitalWrite(PIN_MOTOR_EN, HIGH);            // PWMA=1 habilita el canal A
  motorPhase = abrir ? MOTOR_OPENING : MOTOR_CLOSING;
  motor_start_ms = millis();
}

// Llamada en cada pasada de loop(): detiene el motor al completar el
// travel (~3 s) sin bloquear. Sustituye el delay() bloqueante del
// firmware MicroPython (que por eso necesita alimentar el WDT cada
// 500 ms durante el travel; aquí el loop nunca se bloquea).
void updateMotorTravel() {
  if (motorPhase == MOTOR_STOPPED) return;
  if (millis() - motor_start_ms < ACTUATOR_TRAVEL_MS) return;

  bool abriendo = (motorPhase == MOTOR_OPENING);

  // Fin de recorrido → estado seguro del puente H (igual que hbridge.stop())
  digitalWrite(PIN_MOTOR_EN, LOW);
  digitalWrite(PIN_AIN1, LOW);
  digitalWrite(PIN_AIN2, LOW);
  motorPhase = MOTOR_STOPPED;
  damper_abierta = abriendo;
  logFSM(abriendo ? "Compuertas ABIERTAS - fin de travel, motor detenido"
                  : "Compuertas CERRADAS - fin de travel, motor detenido");

  // Secuencia COOLING (igual que fsm.py): abrir compuertas → ventilador ON
  if (abriendo && fan_pendiente && currentState == STATE_COOLING) {
    setFan(true);
    logFSM("Ventilador ON (MR1238E48B-FSR via MOSFET NMOS)");
  }
  fan_pendiente = false;
}

// Safe state completo: ventilador OFF + motor detenido + travel cancelado
void stopMotorAndFan() {
  setFan(false);
  fan_pendiente = false;
  digitalWrite(PIN_MOTOR_EN, LOW);
  digitalWrite(PIN_AIN1, LOW);
  digitalWrite(PIN_AIN2, LOW);
  motorPhase = MOTOR_STOPPED;
}

// ---------------------------------------------------------------------
// Transiciones de estado con acciones de entrada (coherente con fsm.py)
// ---------------------------------------------------------------------
void transitionTo(State newState) {
  if (currentState == newState) return;

  char transBuf[48];
  snprintf(transBuf, sizeof(transBuf), "TRANSICION: %s -> %s",
           STATE_NAMES[currentState], STATE_NAMES[newState]);
  logFSM(transBuf);

  currentState = newState;

  switch (newState) {
    case STATE_INIT:
      // Acciones de INIT ejecutadas en run_fsm_step() (como _paso_init de fsm.py)
      break;

    case STATE_READING:
      error_counter = 0;
      resetSensors();  // Precarga buffers con muestras frescas
      logFSM("Evaluando sensores NTC...");
      break;

    case STATE_COOLING:
      ticks_cooling_start = millis();
      logFSM("Abriendo compuertas (FIT0803 via TB6612FNG, ~3 s)...");
      startMotorTravel(true);   // AIN1=0, AIN2=1, MOTOR_EN=1 → LED "MOTOR A ABRE"
      fan_pendiente = true;     // Ventilador ON al completar la apertura
      break;

    case STATE_IDLE:
      if (ticks_cooling_start > 0) {
        char durBuf[64];
        snprintf(durBuf, sizeof(durBuf), "ENFRIAMIENTO OK - duracion ciclo: %.1f s",
                 (millis() - ticks_cooling_start) / 1000.0);
        logFSM(durBuf);
        ticks_cooling_start = 0;
      }
      logFSM("Ventilador OFF");
      setFan(false);
      fan_pendiente = false;
      logFSM("Cerrando compuertas (FIT0803 via TB6612FNG, ~3 s)...");
      startMotorTravel(false);  // AIN1=1, AIN2=0, MOTOR_EN=1 → LED "MOTOR A CIERRA"
      break;

    case STATE_ERROR:
      logFSM("SAFE STATE: ventilador OFF + motor detenido");
      stopMotorAndFan();
      error_counter = 0;
      ticks_error = millis();
      break;

    case STATE_LOCKOUT:
      logFSM("LOCKOUT: ventilador OFF + motor detenido (permanente)");
      stopMotorAndFan();
      ticks_error = millis();
      lockout_setpoint = readSetpoint();  // Un cambio de DIP reinicia la FSM
      break;
  }
}
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
void loop() {
  // --- Procesamiento de comandos Serial ---
  if (Serial.available() > 0) {
    String cmd = Serial.readStringUntil('\n');
    cmd.trim();
    if (cmd.startsWith("SET:")) {
      int val = cmd.substring(4).toInt();
      if (val <= 0) {
        override_setpoint = -1;
        Serial.println("Comando recibido: Setpoint manual desactivado (regresa al DIP switch)");
      } else {
        override_setpoint = val;
        Serial.print("Comando recibido: Setpoint manual fijado a ");
        Serial.println(val);
      }
    } else if (cmd.startsWith("TEMP:")) {
      float val = cmd.substring(5).toFloat();
      manual_temp_inject = val;
      do_manual_temp_inject = true;
      Serial.print("Comando recibido: Inyectando temp interna a ");
      Serial.println(val);
    } else if (cmd.startsWith("EXT:")) {
      String valStr = cmd.substring(4);
      if (valStr.equalsIgnoreCase("AUTO") || valStr.equalsIgnoreCase("OFF")) {
        override_temp_ext = -999.0;
        Serial.println("Comando recibido: Temp exterior manual desactivada (usa NTC)");
      } else {
        override_temp_ext = valStr.toFloat();
        Serial.print("Comando recibido: Temp exterior manual fijada a ");
        Serial.println(override_temp_ext);
      }
    }
  }

  // Temporización NO bloqueante del travel del actuador (~3 s)
  updateMotorTravel();

  // Paso de la FSM a 1 Hz con compensación de deriva (sin delay())
  unsigned long now = millis();
  if (now - last_step_time >= STEP_INTERVAL) {
    run_fsm_step();
    logTelemetry();

    unsigned long duration = millis() - now;
    if (duration >= STEP_INTERVAL) {
      last_step_time = millis();          // Ciclo extendido: realinear base
    } else {
      last_step_time += STEP_INTERVAL;    // Ciclo normal: sin deriva acumulada
    }
  }

  // Efecto visual: ventilador a capacidad máxima (parpadeo) en alta temperatura (>= 60°C)
  if (fan_on) {
    if (temp_int >= 60.0) {
      // Reducimos la frecuencia de parpadeo (150ms) para que sea claramente visible en Wokwi
      digitalWrite(PIN_VENT, ((millis() / 150) % 2 == 0) ? HIGH : LOW);
    } else {
      digitalWrite(PIN_VENT, HIGH);
    }
  }
}

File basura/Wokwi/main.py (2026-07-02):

# archivo: main.py  (reemplaza completamente el archivo anterior)
"""
main.py — Entry point del firmware
====================================
Sistema de extracción de aire caliente — Jaguar de México
Candidato: Ing. Jair Molina Arce

Plataformas:
  Simulación : Raspberry Pi Pico (RP2040) — plantilla Wokwi Jaguar
               https://wokwi.com/projects/468207977283145729
  Hardware   : Seeed XIAO RP2350 — sesión en vivo

MicroPython estándar — sin librerías externas.

Carga al MCU (mpremote):
  mpremote connect auto fs cp firmware/*.py :/
  mpremote connect auto reset

Estructura del firmware:
  main.py       — punto de entrada (este archivo)
  fsm.py        — máquina de estados principal (ThermalFSM)
  adc_ntc.py    — lectura de sensores NTC + conversión Beta (GP26, GP27)
  dip_switch.py — lectura DIP switch 3-bit y setpoint (GP0, GP6, GP7)
  hbridge.py    — control TB6612FNG para FIT0803 (GP1, GP2, GP3)
  fan.py        — control MOSFET ventilador MR1238E48B-FSR (GP4)
"""

import sys
import time
from machine import reset

# ── Metadatos del build ───────────────────────────────────────────────
_VERSION   = "1.0.0"
_CANDIDATO = "Ing. Jair Molina Arce"
_FECHA     = "2026-06-30"
_PROYECTO  = "Evaluacion Tecnica — Jaguar de Mexico"


def _banner():
    """
    Imprime banner de identificación en consola serial al arrancar.
    Permite verificar versión y candidato en logs de campo.
    """
    sep = "=" * 54
    print()
    print(sep)
    print("  Sistema de Extraccion de Aire Caliente")
    print("  Gabinete de Telecomunicaciones")
    print("  {}".format(_PROYECTO))
    print("  Candidato : {}".format(_CANDIDATO))
    print("  Version   : {}   Fecha: {}".format(_VERSION, _FECHA))
    try:
        # sys.version puede no estar disponible en todas las builds de MicroPython
        print("  MicroPython: {}".format(sys.version.split(";")[0].strip()))
    except Exception:
        print("  MicroPython: (version no disponible)")
    print(sep)
    print()


def main():
    """
    Función principal. Secuencia de arranque:
      1. Imprimir banner
      2. Importar módulo FSM (detecta archivos faltantes)
      3. Instanciar ThermalFSM (activa WDT)
      4. Ejecutar loop bloqueante run_forever()
      5. En caso de excepción fatal: safe state + reset

    El loop principal a 1 Hz y la compensación de tiempo se gestionan
    internamente en ThermalFSM.run_forever(). Este archivo solo orquesta
    el arranque y maneja la capa de excepciones más externa.
    """
    _banner()

    # Pequeño delay de estabilización de fuente de alimentación
    # (evita lecturas ADC inestables en el primer ciclo)
    time.sleep_ms(300)

    # ── Importar módulo FSM ───────────────────────────────────────────
    # Separar errores de importación (archivo faltante) de errores de ejecución
    try:
        from fsm import ThermalFSM
        print("[BOOT] Modulos del firmware cargados correctamente")
    except ImportError as e:
        print("[CRITICO] Modulo no encontrado: {}".format(e))
        print("[CRITICO] Verificar que todos los .py estan en el MCU")
        print("[CRITICO] Reset en 2 s...")
        time.sleep(2)
        reset()
        return   # Por si reset() no se ejecuta inmediatamente

    # ── Instanciar FSM ────────────────────────────────────────────────
    # ThermalFSM.__init__() activa el WDT y lo registra con hbridge.
    # A partir de aquí el WDT debe alimentarse dentro de 8 s o el MCU reseteará.
    try:
        fsm = ThermalFSM(enable_watchdog=True)
        print("[BOOT] FSM instanciada — WDT activo ({} ms)".format(8000))
    except Exception as e:
        print("[CRITICO] Error al inicializar FSM: {}".format(e))
        print("[CRITICO] Reset en 5 s...")
        time.sleep(5)
        reset()
        return

    # ── Loop principal bloqueante ─────────────────────────────────────
    # run_forever() no retorna en condiciones normales.
    # La gestion del tiempo (1 Hz + compensacion) ocurre internamente en la FSM.
    try:
        fsm.run_forever()

    except KeyboardInterrupt:
        # Solo alcanzable en sesion REPL/debug; en produccion no ocurre.
        print("\n[MAIN] Detenido por usuario (Ctrl+C) — activando safe state")
        _safe_state_emergencia()
        print("[MAIN] Sistema detenido. WDT expirara en ~8 s.")

    except Exception as e:
        # Excepcion que escapo del loop de run_forever() sin ser capturada
        # por step() — no deberia ocurrir, pero es la ultima linea de defensa.
        print("\n[CRITICO] Excepcion fatal no capturada: {}".format(e))
        _safe_state_emergencia()
        print("[CRITICO] Reset en 5 s...")
        time.sleep(5)
        reset()


def _safe_state_emergencia():
    """
    Aplica safe state directamente sin pasar por la FSM.
    Solo para casos en que la FSM no esta disponible o no responde.
    """
    try:
        from fan     import fan
        from hbridge import hbridge
        fan.off()
        hbridge.stop()
        print("[MAIN] Safe state aplicado: ventilador OFF, motor detenido")
    except Exception as e:
        print("[MAIN] No se pudo aplicar safe state: {}".format(e))


# ── Entry point ───────────────────────────────────────────────────────
# MicroPython ejecuta main.py automaticamente al encender.
main()

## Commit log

2026-07-02 Initial commit for Jaguar MX project
    [PCB.kicad_pcb, PCB.kicad_sch, PCB_backup_v1.kicad_pcb]
2026-07-02 feat: implement FSM temperature injection, delays, and visual LED blinking effect for Wokwi
2026-07-02 feat: implement serial commands to override setpoint and inject temperature manually
2026-07-02 feat: add EXT command to manually override exterior temperature
2026-07-02 refactor: remove automatic temperature injection on DIP switch change
2026-07-02 docs: complement technical schedule docx with Wokwi simulation improvements (serial commands, LED blinking, and non-blocking FSM)
2026-07-02 chore: clean up project, remove temporary scripts/files, and add final audit report
    [PCB.kicad_sch]
2026-07-02 Limpieza de archivos innecesarios de PCB y creacion de guia de enrutado
    [PCB.kicad_pcb, PCB.kicad_sch, PCB_backup_v1.kicad_pcb]
2026-07-03 Fix J5/J6 topology, add connector labels, verify ERC, fill title block
    [PCB.kicad_sch]
2026-07-03 chore: version 1.1.2 - Agregados planos de cobre y organizacion de archivos
    [PCBv2.kicad_pcb, PCBv3.kicad_pcb, PCBv4.kicad_pcb]
